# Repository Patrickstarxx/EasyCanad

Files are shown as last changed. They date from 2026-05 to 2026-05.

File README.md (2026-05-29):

# EasyCanad — 鸭翼飞行器 AOA 反馈控制器

基于 Arduino 的鸭翼（canard）飞行器控制系统，支持 AOA 攻角传感器反馈、单路 PWM 遥控输入（俯仰/升降通道），以及 EEPROM 一键零位校准。

## 功能特性

- **AOA 反馈稳定**：通过模拟攻角传感器闭环控制鸭翼，自动对准来流
- **RC 遥控叠加**：俯仰（升降）通道 PWM 输入，在 AOA 稳定基础上叠加人工机动
- **一键零位校准**：按下按钮即记录当前攻角为零位，保存到 EEPROM，断电不丢失
- **200Hz 控制刷新**：5ms 控制周期，一阶低通滤波平滑传感器数据
- **串口调试输出**：115200 baud 实时输出 AOA、RC 脉宽、鸭翼指令角度

## 硬件连接

### 引脚接线表

| Arduino 引脚 | 连接设备 | 说明 |
|---|---|---|
| **A0** | AOA 攻角传感器 | 模拟输入 0~5V，对应 -180°~+180° |
| **D2** | RC 接收机 — 俯仰(升降)通道 | PWM 输入，INT0 中断捕获 |
| **D4** | 标定按钮 | 按下接 GND（INPUT_PULLUP，常开） |
| **D9** | 鸭翼舵机 | PWM 输出 500~2500μs |

### 接线示意

```
                      ┌──────────────────┐
                      │    Arduino       │
                      │                  │
AOA 传感器 ────────── │ A0           D9  │ ─── 鸭翼舵机
RC 俯仰通道 ───────── │ D2 (INT0)        │
标定按钮 ──────────── │ D4               │
                      │                  │
5V ────────────────── │ 5V           GND │ ─── GND
                      └──────────────────┘
```

> **注意**：舵机供电建议使用独立 BEC，不要从 Arduino 5V 引脚取电，否则大电流可能导致复位。

## 编译与烧录

1. 用 **Arduino IDE** 打开 `EasyCanad.ino`
2. 选择开发板：**Arduino Nano**（ATmega328P）
3. `Servo.h` 和 `EEPROM.h` 为 IDE 自带，无需额外安装
4. 点击 **上传**

## PCB 文件

PCB 设计文件位于 `hardware/` 目录，包含：

- `Schematic_EasyCanad.json`：立创 EDA / EasyEDA 原理图源文件
- `PCB_EasyCanad.json`：立创 EDA / EasyEDA PCB 源文件
- `README.txt`：离线文件导入说明

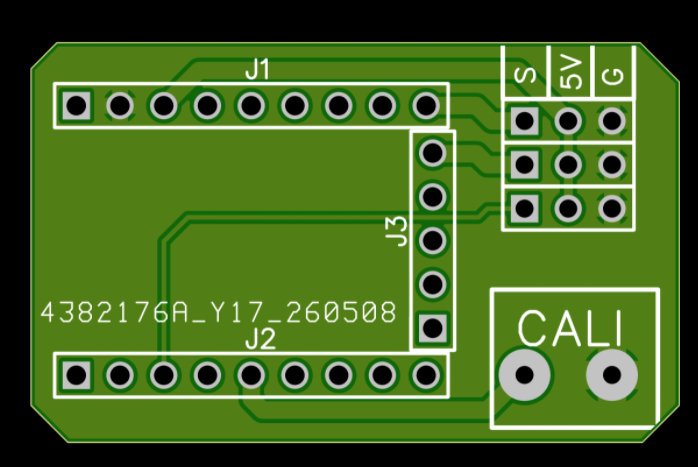
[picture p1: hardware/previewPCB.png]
PCB 3D 预览


在立创 EDA 编辑器中，可通过 **文件 > 打开 > 立创EDA...** 选择对应 JSON 文件导入，并保存到自己的工程中继续编辑或导出 Gerber。

完整离线包也保留在 `PCB-EasyCanad.zip` 中方便分发。

## 调试

### 串口监视器

烧录后打开串口监视器（115200 baud），约每 100ms 输出一行：

```
AOAraw=85.32, Zero=87.10, AOA=-1.78, RC=1502, Add=1.8, Cmd=-4.2, ServoUs=1463
```

各字段含义：

| 字段 | 含义 | 单位 |
|---|---|---|
| `AOAraw` | 传感器原始角度（未减零位） | deg |
| `Zero` | 当前零位校准值 | deg |
| `AOA` | 滤波后的相对攻角 | deg |
| `RC` | 俯仰通道原始脉宽 | μs |
| `Add` | RC 映射的叠加角度 | deg |
| `Cmd` | 鸭翼最终指令角度 | deg |
| `ServoUs` | 输出到舵机的脉宽 | μs |

### 常见调参

在代码开头的参数配置区直接修改：

| 参数 | 默认值 | 说明 |
|---|---|---|
| `aoaFilterAlpha` | 0.15 | 滤波系数：越小越平滑但响应慢，0.05~0.3 |
| `rcAuthorityDeg` | 90 | 遥控最大叠加角度，杆量 100% 时叠加多少度 |
| `canardLimitDeg` | 90 | 鸭翼最大偏转角，防止机械干涉 |
| `aoaMinDeg` / `aoaMaxDeg` | -180 / 180 | 传感器 0~5V 对应的角度范围 |

## 标定流程

1. 将飞行器放置在**实际飞行的零攻角姿态**（即巡航姿态）
2. 按下标定按钮（D4 接 GND），串口输出 `CAL saved. zero(deg)= xx.xxx`
3. 零位已写入 EEPROM，之后每次上电自动加载

## 控制算法

```
舵机角度 = -1.2 × AOA(滤波) - RC遥控叠加

输出脉宽 = map(角度, -90°, 90°, 500μs, 2500μs)
```

AOA 系数 `1.2` 为控制增益，使鸭翼对攻角变化有一定超前响应。可根据实际飞行手感调整。

## 项目结构

```
EasyCanad/
├── EasyCanad.ino              # 主程序
├── BOM.md                     # 物料清单（含购买链接）
├── PCB-EasyCanad.zip          # PCB 离线包（发布用）
├── README.md                  # 本文件
├── .gitignore
├── hardware/
│   ├── previewPCB.png         # PCB 3D 预览图
│   ├── Schematic_EasyCanad.json
│   ├── PCB_EasyCanad.json
│   └── README.txt
├── cad/
│   ├── vane-blade.STEP        # AOA 传感器叶片 3D 模型
│   └── vane-body.SLDPRT       # AOA 传感器主体 3D 模型
└── archive/
    ├── firmware-v1-no-calibration.ino    # 早期版本（无零位校准）
    └── firmware-v2-with-calibration.ino  # 零位校准版本（历史备份）
```

> `archive/` 目录存放旧版固件代码，仅供历史参考。当前使用的固件为根目录下的 `EasyCanad.ino`。

## 许可证

MIT License

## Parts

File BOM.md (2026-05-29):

# EasyCanad 物料清单 (BOM)

## 主控

| 序号 | 名称 | 规格/型号 | 数量 | 购买链接 |
|---|---|---|---|---|
| 1 | Arduino Nano 开发板 | Nano V3 ATmega328P | 1 | [淘宝](https://e.tb.cn/h.RfFKSwqKJCgVCY3?tk=hYVv5C3pElp) |

## 传感器

| 序号 | 名称 | 规格/型号 | 数量 | 购买链接 |
|---|---|---|---|---|
| 2 | AOA 攻角传感器 | 霍尔角度传感器，360° 转 0~5V 输出 | 1 | [淘宝](https://e.tb.cn/h.RfFLycpNjRvoOrk?tk=8pXX5C3p0ex) |
| 3 | RC 接收机 | PWM 输出，至少 1 通道（升降） | 1 | — |

## 执行器

| 序号 | 名称 | 规格/型号 | 数量 | 备注 |
|---|---|---|---|---|
| 4 | 鸭翼舵机 | 标准舵机，500~2500μs | 1 | 接 D9 |

## 其他

| 序号 | 名称 | 规格/型号 | 数量 | 备注 |
|---|---|---|---|---|
| 5 | 标定按钮 | 轻触开关，常开，按下接 GND | 1 | 接 D4 (INPUT_PULLUP) |
| 6 | 电源模块 | BEC 5V / 2A 以上 | 1 | 给 Arduino 和舵机供电 |
| 7 | 杜邦线 / 排针 | 公母各若干 | 若干 | 接线用 |

## 3D 打印 / 结构件

| 序号 | 名称 | 文件 | 数量 | 备注 |
|---|---|---|---|---|
| 8 | 风标大叶片 | `cad/vane-blade.STEP` | 1 | AOA 传感器叶片 |
| 9 | 风标主体 | `cad/vane-body.SLDPRT` | 1 | AOA 传感器主体 |

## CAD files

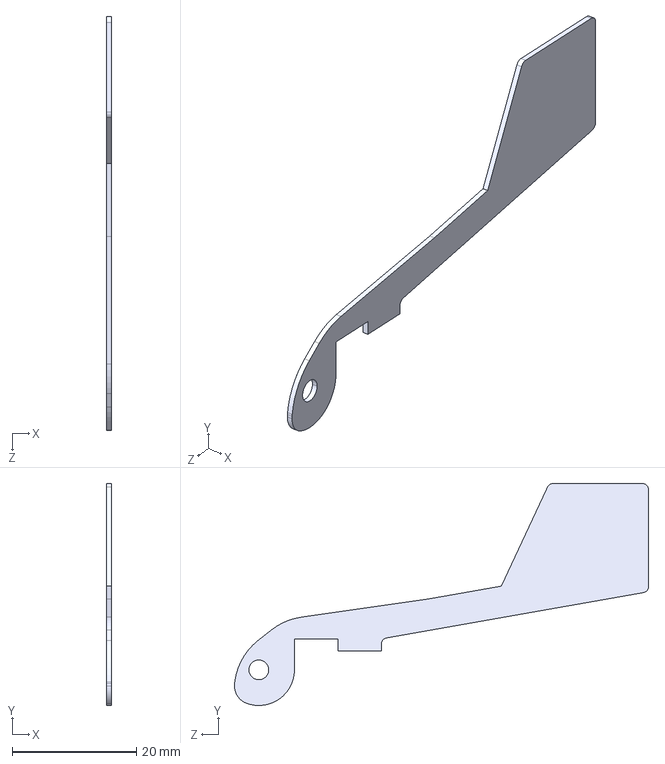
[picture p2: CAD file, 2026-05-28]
cad/vane-blade.STEP
0.8 x 35.7 x 66.7 mm

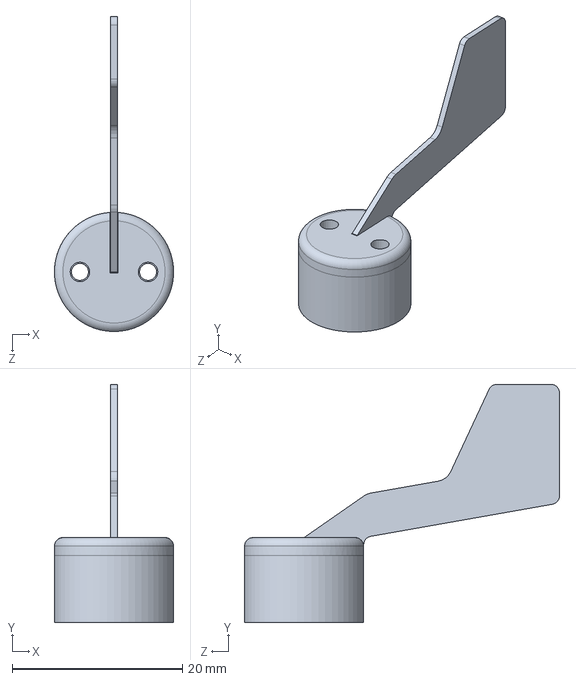
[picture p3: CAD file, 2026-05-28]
cad/vane-body.SLDPRT
14.0 x 28.0 x 37.0 mm

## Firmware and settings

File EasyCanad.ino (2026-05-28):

#include <Arduino.h>
#include <Servo.h>
#include <EEPROM.h>

// ===================== 引脚定义 =====================
const uint8_t PIN_AOA_SENSOR = A0;
const uint8_t PIN_SERVO      = 9;
const uint8_t PIN_RC_IN      = 2;
const uint8_t PIN_CAL_BTN    = 4;

// ===================== 参数配置 =====================
float aoaMinDeg = -180.0f;
float aoaMaxDeg =  180.0f;
float aoaOffsetDeg = 0.0f;

const int RC_MIN_US = 1000;
const int RC_MAX_US = 2000;
const int RC_MID_US = 1500;

float rcAuthorityDeg = 90.0f;
float canardLimitDeg = 90.0f;     // 舵机控制范围 -90~+90
float aoaFilterAlpha = 0.15f;
const uint32_t CONTROL_PERIOD_US = 5000;

// ===================== EEPROM标定参数 =====================
const int EEPROM_ADDR_MAGIC = 0;
const int EEPROM_ADDR_ZERO  = EEPROM_ADDR_MAGIC + sizeof(uint32_t);
const uint32_t CAL_MAGIC = 0xA0A0BEEF;
float sensorZeroDeg = 0.0f;

// ===================== RC测量（中断） =====================
volatile uint32_t rcRiseMicros = 0;
volatile uint16_t rcPulseUs = 1500;
volatile bool rcUpdated = false;

Servo canardServo;

// ===================== 工具函数 =====================
static inline float clampf(float x, float lo, float hi) {
  if (x < lo) return lo;
  if (x > hi) return hi;
  return x;
}

float mapFloat(float x, float in_min, float in_max, float out_min, float out_max) {
  return (x - in_min) * (out_max - out_min) / (in_max - in_min) + out_min;
}

// 角度归一化到 [-180, 180)
float wrap180(float a) {
  while (a >= 180.0f) a -= 360.0f;
  while (a < -180.0f) a += 360.0f;
  return a;
}

// 计算相对零位后的AOA，并限制到 [-90, 90]
float getAOAdeg(float aoaRawDeg, float sensorZeroDeg) {
  float rel = wrap180(aoaRawDeg - sensorZeroDeg);
  return clampf(rel, -90.0f, 90.0f);
}

// AOA/舵面角度 -> 舵机脉宽
int degToServoUs(float deg) {
  deg = clampf(deg, -90.0f, 90.0f);
  return (int)(mapFloat(deg, -90.0f, 90.0f, 500.0f, 2500.0f) + 0.5f);
}

void rcISR() {
  if (digitalRead(PIN_RC_IN) == HIGH) {
    rcRiseMicros = micros();
  } else {
    uint32_t now = micros();
    uint32_t width = now - rcRiseMicros;
    if (width >= 800 && width <= 2200) {
      rcPulseUs = (uint16_t)width;
      rcUpdated = true;
    }
  }
}

void loadCalibration() {
  uint32_t magic = 0;
  EEPROM.get(EEPROM_ADDR_MAGIC, magic);
  if (magic == CAL_MAGIC) {
    EEPROM.get(EEPROM_ADDR_ZERO, sensorZeroDeg);
    if (isnan(sensorZeroDeg) || sensorZeroDeg < -1000 || sensorZeroDeg > 1000) {
      sensorZeroDeg = 0.0f;
    }
  } else {
    sensorZeroDeg = 0.0f;
  }
}

void saveCalibration(float zeroDeg) {
  EEPROM.put(EEPROM_ADDR_ZERO, zeroDeg);
  uint32_t magic = CAL_MAGIC;
  EEPROM.put(EEPROM_ADDR_MAGIC, magic);
  sensorZeroDeg = zeroDeg;
}

bool isCalButtonPressedEvent() {
  static uint8_t stableState = HIGH;
  static uint8_t lastRead = HIGH;
  static uint32_t tChange = 0;

  uint8_t now = digitalRead(PIN_CAL_BTN);

  if (now != lastRead) {
    lastRead = now;
    tChange = millis();
  }

  if ((millis() - tChange) > 20) {
    if (now != stableState) {
      stableState = now;
      if (stableState == LOW) {
        return true;
      }
    }
  }
  return false;
}

void setup() {
  pinMode(PIN_RC_IN, INPUT);
  pinMode(PIN_AOA_SENSOR, INPUT);
  pinMode(PIN_CAL_BTN, INPUT_PULLUP);

  canardServo.attach(PIN_SERVO);
  attachInterrupt(digitalPinToInterrupt(PIN_RC_IN), rcISR, CHANGE);

  Serial.begin(115200);
  loadCalibration();
}

void loop() {
  static uint32_t lastControlUs = 0;
  uint32_t nowUs = micros();

  // ========= 标定 =========
  if (isCalButtonPressedEvent()) {
    int rawNow = analogRead(PIN_AOA_SENSOR);
    float voltageNow = rawNow * (5.0f / 1023.0f);
    float aoaRawDegNow = mapFloat(voltageNow, 0.0f, 5.0f, aoaMinDeg, aoaMaxDeg) + aoaOffsetDeg;

    saveCalibration(aoaRawDegNow);
    Serial.print("CAL saved. zero(deg)= ");
    Serial.println(sensorZeroDeg, 3);
  }

  if ((uint32_t)(nowUs - lastControlUs) >= CONTROL_PERIOD_US) {
    lastControlUs = nowUs;

    // ---- 1) 读取传感器 ----
    int raw = analogRead(PIN_AOA_SENSOR);
    float voltage = raw * (5.0f / 1023.0f);
    float aoaRawDeg = mapFloat(voltage, 0.0f, 5.0f, aoaMinDeg, aoaMaxDeg) + aoaOffsetDeg;

    // ---- 2) 零位补偿 + 限幅到 [-90, 90] ----
    float aoaDeg = getAOAdeg(aoaRawDeg, sensorZeroDeg);

    // ---- 3) 滤波 ----
    static float aoaFilt = 0.0f;
    static bool aoaInit = false;
    if (!aoaInit) {
      aoaFilt = aoaDeg;
      aoaInit = true;
    } else {
      aoaFilt = aoaFilt + aoaFilterAlpha * (aoaDeg - aoaFilt);
    }

    // ---- 4) RC输入 ----
    uint16_t rcUsLocal;
    noInterrupts();
    rcUsLocal = rcPulseUs;
    interrupts();

    rcUsLocal = constrain(rcUsLocal, RC_MIN_US, RC_MAX_US);

    float rcNorm;
    if (rcUsLocal >= RC_MID_US) {
      rcNorm = (float)(rcUsLocal - RC_MID_US) / (float)(RC_MAX_US - RC_MID_US);
    } else {
      rcNorm = -(float)(RC_MID_US - rcUsLocal) / (float)(RC_MID_US - RC_MIN_US);
    }
    rcNorm = clampf(rcNorm, -1.0f, 1.0f);
    float rcAddDeg = rcNorm * rcAuthorityDeg;

    // ---- 5) 合成命令，并限制到 [-90, 90] ----
    float canardCmdDeg = -1.2f*aoaFilt - rcAddDeg;
    canardCmdDeg = clampf(canardCmdDeg, -90.0f, 90.0f);

    // ---- 6) 输出舵机 ----
    int servoUs = degToServoUs(canardCmdDeg);
    canardServo.writeMicroseconds(servoUs);

    // 调试输出
    static uint8_t div = 0;
    if (++div >= 20) {
      div = 0;
      Serial.print("AOAraw=");
      Serial.print(aoaRawDeg, 2);
      Serial.print(", Zero=");
      Serial.print(sensorZeroDeg, 2);
      Serial.print(", AOA=");
      Serial.print(aoaFilt, 2);
      Serial.print(", RC=");
      Serial.print(rcUsLocal);
      Serial.print(", Add=");
      Serial.print(rcAddDeg, 2);
      Serial.print(", Cmd=");
      Serial.print(canardCmdDeg, 2);
      Serial.print(", ServoUs=");
      Serial.println(servoUs);
    }
  }
}

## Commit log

2026-05-28 初始提交：鸭翼混控控制器，含BOM/README/3D模型
    [风标-大叶片.STEP, 风标.SLDPRT]
2026-05-28 回滚为单通道版本 + 更新BOM含购买链接 + 更新README
2026-05-28 添加PCB离线文件并更新README
2026-05-29 chore: reorganize repo structure
    - Rename 模型/ to cad/ with English file names
    - Extract PCB files to hardware/ directory
    - Move old firmware backups to archive/ with .ino extension
    - Update README.md with new structure and PCB preview
    - Update BOM.md with corrected file paths
    [vane-blade.STEP, vane-body.SLDPRT]
2026-10-24 docs: clarify prototype and active development status
2026-10-27 feat: add mirrored canard servo output on D10
